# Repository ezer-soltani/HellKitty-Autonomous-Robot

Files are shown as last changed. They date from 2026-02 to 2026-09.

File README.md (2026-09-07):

# 🐱 HellKitty — Autonomous Combat Mobile Robot
### High-Performance Embedded Robotics Platform: STM32G431 (ARM Cortex-M4F @ 170MHz) | FreeRTOS Real-Time Architecture | Custom 4-Layer PCB

<p align="center">
  HellKitty Autonomous Mobile Robot
</p>

<p align="center">
  
  
  
  
  
</p>

---

## ⚡ Executive Engineering Summary

**HellKitty** is an industrial-grade autonomous combat robot engineered for high-speed table-top arena navigation ("Cat & Mouse" adversarial game logic). Designed from bare silicon up to deterministic application-layer control, the platform combines custom **4-layer power/signal mixed PCB hardware**, **bare-metal C peripheral drivers**, and a **preemptive FreeRTOS real-time architecture**.

The robot executes simultaneous 360° laser perception (YDLIDAR X2 @ 115.2 kbps via DMA), 4-quadrant edge/void Time-of-Flight monitoring (VL53L0X @ 100 Hz), high-G collision detection (ADXL343 accelerometer), dual closed-loop velocity PID regulation (TIM2/TIM4 hardware encoder quadrature decoding @ 100 Hz), and dynamic state-machine tactical transitions under strict deterministic latency constraints.

```
+----------------------------------------------------------------------------------------------------+
|                                    HELLKITTY SYSTEM BENCHMARKS                                     |
+--------------------------+-------------------------------------------------------------------------+
| Core Frequency           | 170 MHz (ARM Cortex-M4F with hardware FPU & DSP instructions)           |
| Control Loop Frequency   | 100 Hz deterministic periodic execution (vTaskDelayUntil)               |
| Edge Safety Latency      | < 10 ms hardware-level emergency stop & auto-evacuation override        |
| LiDAR Data Stream        | Circular DMA buffer (1024 B) with zero-copy packet state-machine parser |
| Sensor Bus Topology      | I2C1 (Fast Mode 400 kHz) with FreeRTOS Mutex Priority Inheritance       |
| Dynamic Power Delivery   | 5.5V-12V input -> 5V @ 3A Buck (MP1475) -> 3.3V Low-Noise LDO (BU33SD5)  |
| Motor Control Drive      | Dual ZXBM5210-SP H-Bridges (3A peak, dynamic braking, 20 kHz PWM)       |
+--------------------------+-------------------------------------------------------------------------+
```

---

## 🏗️ System Architecture

The robot's firmware and hardware layers are decoupled through strict hardware abstraction and thread-safe real-time communication mechanisms:

```mermaid
graph TD
    %% Subsystem Grouping
    subgraph SENSORS["Perception & Telemetry Hardware"]
        LIDAR["YDLIDAR X2\n(360° 2D Laser Rangefinder)"]
        TOF["4x VL53L0X ToF\n(Quadrants: FL, FR, RL, RR)"]
        IMU["ADXL343\n(3-Axis Accelerometer)"]
        ENC["2x Quadrature Encoders\n(2048 CPR / Wheel)"]
        BT["HC-05 Bluetooth\n(Telemetry / Remote Shell)"]
    end

    subgraph HARDWARE_IF["STM32G431 Microcontroller Peripherals"]
        UART2_DMA["USART2 + Circular DMA\n(115200 baud, 1024B Buffer)"]
        I2C1_BUS["I2C1 Fast Mode (400kHz)\n(Addresses: 0x54, 0x56, 0x58, 0x5A, 0xA6)"]
        TIM_ENC["TIM2 (32-bit) & TIM4 (16-bit)\nHardware Encoder Interface Mode"]
        UART3_IT["USART3 RX Interrupt\n(Byte-by-byte parser)"]
        TIM3_PWM["TIM3 4-Channel PWM\n(20 kHz Motor Drive)"]
        GPIO_CTRL["GPIO Output / Status LEDs\n(XSHUT, Brake, Status LEDs)"]
    end

    subgraph RTOS_LAYER["FreeRTOS Preemptive Kernel"]
        MUTEX_I2C{{"xI2C1Mutex\n(Priority Inheritance)"}}
        MUTEX_UART{{"xUARTMutex\n(Thread-Safe Printf)"}}
        
        TASK_SAFETY["vSafetyTask\n(Priority 3 | 100 Hz)\nEdge Void & Fault Protection"]
        TASK_CONTROL["vControlTask\n(Priority 4 | 100 Hz)\nPID, Odometry, Motor Output"]
        TASK_LIDAR["vLidarTask\n(Priority 2 | 10-100 Hz)\nDMA Stream & Cluster Tracker"]
        TASK_IMU["vImuTask\n(Priority 1 | 20 Hz)\nShock / Tap Detection (>3.5G)"]
        
        OVERRIDE_FLAG[["g_safety_override\n(Atomic Override Flag)"]]
    end

    subgraph CONTROL_LOGIC["Control & Algorithmic Layer"]
        FSM["Strategy FSM\n(SEARCH / ATTACK / FLEE)"]
        PID_L["Left Velocity PID\n(Kp=5.0, Ki=20.0, Anti-Windup)"]
        PID_R["Right Velocity PID\n(Kp=5.0, Ki=20.0, Anti-Windup)"]
        ODOM["Runge-Kutta Odometry\n(x, y, θ state integration)"]
        CLUST["Geometric Clustering\n(Width Filter: 50-300mm)"]
    end

    subgraph ACTUATION["Actuators & Power Systems"]
        H_BRIDGE["Dual ZXBM5210-SP H-Bridges\n(Reversible DC Motor Drivers)"]
        MOTORS["2x Micro Metal Gearmotors\n(Differential Drive Chassis)"]
        STATUS_LED["Cat/Mouse Status Indicator LEDs"]
    end

    %% Connectivity
    LIDAR --> UART2_DMA
    TOF --> I2C1_BUS
    IMU --> I2C1_BUS
    ENC --> TIM_ENC
    BT --> UART3_IT

    UART2_DMA --> TASK_LIDAR
    I2C1_BUS <--> MUTEX_I2C
    MUTEX_I2C <--> TASK_SAFETY
    MUTEX_I2C <--> TASK_IMU
    UART3_IT --> FSM
    TIM_ENC --> TASK_CONTROL

    TASK_LIDAR --> CLUST --> FSM
    TASK_IMU -->|Role Switch Event| FSM
    FSM --> TASK_CONTROL
    
    TASK_CONTROL --> PID_L & PID_R --> TIM3_PWM
    TASK_CONTROL --> ODOM
    TASK_SAFETY -->|Triggers Emergency Evasion| OVERRIDE_FLAG
    OVERRIDE_FLAG -.->|Forces Motor Override| TASK_CONTROL

    TIM3_PWM --> H_BRIDGE --> MOTORS
    GPIO_CTRL --> STATUS_LED
```

---

## ⏱️ FreeRTOS Multitasking & Real-Time Scheduling

The firmware uses **FreeRTOS v10.3.1** with dynamic memory allocation, preemptive scheduling, and priority-inheritance mutexes to guarantee deterministic timing across all subsystems.

### Task Execution Matrix

| Task Name | Priority | Periodicity / Trigger | Stack Size | Shared Resources / IPC | Functional Responsibility |
| :--- | :---: | :---: | :---: | :---: | :--- |
| `vControlTask` | **4 (Highest)** | **100 Hz (10 ms)**<br>`vTaskDelayUntil` | 512 words<br>(2048 B) | Hardware Timers (TIM2/3/4), Target Speeds (`target_speed_lin_x`, `target_speed_ang_z`) | Reads wheel encoders, updates Runge-Kutta odometry, executes dual velocity PID loops with integral anti-windup, computes PWM duty cycles, and applies motor ramping. |
| `vSafetyTask` | **3 (High)** | **100 Hz (10 ms)**<br>Continuous Polling | 256 words<br>(1024 B) | `xI2C1Mutex`, `g_safety_override`, `STATUS_SOURIS_LED` | Polls 4x VL53L0X ToF range registers. If distance to table surface exceeds 200 mm (void/cliff detected), asserts atomic override flag, cuts motor PWM, and commands automated pivot-and-reverse escape trajectory. |
| `vLidarTask` | **2 (Normal)** | **10 Hz (100 ms)**<br>(DMA Polled @ 100 Hz) | 512 words<br>(2048 B) | `huart2` Circular DMA buffer, `xUARTMutex`, `g_target` | Processes raw bytes from circular DMA, validates packet headers (`0xAA 0x55`) and XOR checksums, performs geometric angle correction, clusters contiguous obstacle points, and tracks closest target. |
| `vImuTask` | **1 (Low)** | **20 Hz (50 ms)**<br>Periodic Delay | 256 words<br>(1024 B) | `xI2C1Mutex`, `Strategy_ToggleRole()` | Reads ADXL343 3-axis acceleration registers over I2C. Evaluates hardware `SINGLE_TAP` shock interrupt (>3.5G threshold) with 2000 ms debounce to switch between Cat (Predator) and Mouse (Prey) combat states. |

### Shared Resource Arbitration & Synchronization

```c
// Example: Thread-safe I2C bus acquisition with Priority Inheritance
if (xSemaphoreTake(xI2C1Mutex, portMAX_DELAY) == pdTRUE) {
    status = ADXL343_ReadAxes(&hi2c1, &accel_data);
    if (ADXL343_CheckShock(&hi2c1) && g_safety_override == 0) {
        shock_detected = 1;
    }
    xSemaphoreGive(xI2C1Mutex);
}
```

1. **I2C1 Bus Contention:** The `xI2C1Mutex` protects the single I2C peripheral shared between the 4x VL53L0X ToF rangefinders and the ADXL343 IMU. Priority inheritance guarantees that if the low-priority `vImuTask` holds the bus when `vSafetyTask` wakes up, `vImuTask` temporarily inherits Priority 3, preventing unbounded priority inversion.
2. **LiDAR Circular DMA Buffer:** Direct Memory Access on USART2 writes directly to a 1024-byte SRAM ring buffer without CPU interrupt thrashing. The task tracks hardware `CNDTR` counter offsets to parse complete frames asynchronously.
3. **Safety Override Interlock:** An atomic flag `g_safety_override` decouples normal FSM navigation from the anti-fall maneuver. When asserted, `vControlTask` suspends trajectory setpoints until the robot returns to safe bounds.

---

## 🖨️ Hardware Design & Custom 4-Layer PCB

The robot is built around a custom **4-layer impedance-controlled PCB** engineered in KiCad 9.0, optimized for high current density, low EMI, and clean power distribution.

<p align="center">
  4-Layer PCB 3D CAD Model
</p>

### PCB Layer Stackup (1.6 mm Total Thickness, FR4)

| Layer | Name | Type | Copper Thickness | Dielectric Spacing | Functional Allocation |
| :---: | :--- | :---: | :---: | :---: | :--- |
| **L1** | `F.Cu` (Top) | Signal | 35 µm (1 oz) | — | High-speed digital signals (SWD, USART, I2C, SPI), MCU breakout, sensor connectors. |
| **—** | Dielectric 1 | Prepreg (FR4) | — | 0.10 mm (\(\varepsilon_r = 4.5\)) | High capacitive coupling to ground plane. |
| **L2** | `In1.Cu` (Inner 1) | Power / Plane | 35 µm (1 oz) | — | **Continuous Solid Ground Plane (GND)** for unbroken return current paths and EMI reduction. |
| **—** | Dielectric 2 | Core (FR4) | — | 1.24 mm (\(\varepsilon_r = 4.5\)) | Structural core isolation. |
| **L3** | `In2.Cu` (Inner 2) | Power / Plane | 35 µm (1 oz) | — | **Power Distribution Plane (PWR)**: Split polygon pours for `+5V`, `+3.3V`, and `VBAT`. |
| **—** | Dielectric 3 | Prepreg (FR4) | — | 0.10 mm (\(\varepsilon_r = 4.5\)) | High capacitive coupling to bottom layer. |
| **L4** | `B.Cu` (Bottom) | Signal | 35 µm (1 oz) | — | High-current motor H-bridge power routing, thermal relief dissipation, and test points. |

### Component & Power Distribution Architecture

| Subsystem | Component / IC | Interface | Specifications & Operational Role |
| :--- | :--- | :---: | :--- |
| **MCU** | **STM32G431CBU6** (UFQFPN48) | SWD / STDC14 | ARM Cortex-M4F @ 170 MHz, 128 KB Flash, 32 KB SRAM, hardware FPU/DSP, CORDIC math unit. |
| **Step-Down Buck** | **MPS MP1475DJ-LF-P** | Switching Reg | 500 kHz synchronous buck converter converting 2S/3S LiPo battery (7.4V–11.1V) to a stable 5.0V @ 3.0A rail. |
| **Low-Noise LDO** | **ROHM BU33SD5WG-TR** | Linear Reg | High PSRR, ultra-low dropout linear regulator stepping down 5.0V to 3.3V for MCU core and analog peripherals. |
| **Motor Drivers** | **2x Diodes Inc. ZXBM5210-SP** | TIM3 PWM / GPIO | Reversible H-Bridge drivers (3V–18V, 0.85A continuous, 3.0A peak, SOIC-8EP) with dynamic braking and cross-conduction protection. |
| **LiDAR Sensor** | **YDLIDAR X2** | USART2 + DMA | 360° 2D triangulation laser rangefinder (8 Hz rotational scan frequency, 0.12m–8.0m range, 3 kHz sample rate). |
| **Cliff / ToF Array** | **4x STMicroelectronics VL53L0X** | I2C1 + 4x XSHUT | Time-of-Flight ranging sensors dynamically re-addressed (0x54, 0x56, 0x58, 0x5A) for four-corner table edge monitoring. |
| **IMU / Shock** | **Analog Devices ADXL343BCCZ** | I2C1 + INT2 | 3-axis ultra-low power digital accelerometer configured for `SINGLE_TAP` interrupt capture (>3.5G collision detection). |
| **Encoders** | **2x Quadrature Optical/Magnetic** | TIM2 / TIM4 | Dual-channel differential quadrature encoder feedback (2048 counts per wheel revolution in 4x mode). |
| **Telemetry / Comms**| **HC-05 Bluetooth Module** | USART3 @ 9600bd | Bidirectional UART telemetry bridge for real-time telemetry streaming and remote state control. |

### KiCad Schematic Sheet Index

The complete schematic design is partitioned into modular hierarchical sheets inside [`hardware/`](hardware/):

| Schematic Sheet | Source File | Description |
| :--- | :--- | :--- |
| **Root Top Sheet** | [`Projet_Robot.kicad_sch`](hardware/Projet_Robot.kicad_sch) | Top-level interconnections, hierarchical bus links, and module connectors. |
| **MCU & Clocks** | [`µcontrolleur.kicad_sch`](hardware/µcontrolleur.kicad_sch) | STM32G431 pinout, STDC14 debug connector, external 8 MHz crystal, bypass capacitors, and status LEDs. |
| **Power Regulators** | [`regulateurs.kicad_sch`](hardware/regulateurs.kicad_sch) | MP1475 buck regulator, BU33SD5 LDO, LC output filtering, reverse-polarity protection, and slide power switch. |
| **Sensor Array** | [`capteur.kicad_sch`](hardware/capteur.kicad_sch) | 4x VL53L0X ToF connectors with XSHUT lines, ADXL343 accelerometer layout, and YDLIDAR / HC-05 headers. |
| **Motor Driver 1 & 2** | [`moteur1.kicad_sch`](hardware/moteur1.kicad_sch) | Dual ZXBM5210-SP H-Bridges, flyback suppression capacitors, test points, and JST-XH encoder/motor connectors. |

---

## 💻 Low-Level Driver & Algorithmic Implementation

### 1. YDLIDAR X2 Circular DMA Driver & Packet Parsing

The LiDAR stream transmits continuous variable-length point frames at 115200 baud over `USART2`. To eliminate CPU byte-by-byte interrupts, DMA operates in circular ring-buffer mode (`LIDAR_DMA_BUFFER_SIZE = 1024`):

```c
// Zero-overhead ring buffer processing in vLidarTask
uint16_t pos = LIDAR_DMA_BUFFER_SIZE - __HAL_DMA_GET_COUNTER(huart2.hdmarx);
if (pos != old_pos) {
    if (pos > old_pos) {
        ydlidar_process_data(&lidar_dma_buffer[old_pos], pos - old_pos);
    } else {
        ydlidar_process_data(&lidar_dma_buffer[old_pos], LIDAR_DMA_BUFFER_SIZE - old_pos);
        if (pos > 0) ydlidar_process_data(&lidar_dma_buffer[0], pos);
    }
    old_pos = pos;
}
```

#### Frame Decoding State Machine & Validation
1. **Header Synchronization:** Scans for sequence `0xAA 0x55`.
2. **Header Parsing:** Reads Packet Type (`CT`), Sample Count (`LSN`), First Sample Angle (`FSA`), and Last Sample Angle (`LSA`).
3. **XOR Checksum Verification:** Computes 16-bit folded XOR checksum over the full packet structure and rejects corrupted frames:
   $$\text{Checksum} = \bigoplus_{i=0}^{N-1} \text{Word}_i$$
4. **Geometric Angle Correction:** Corrects triangulation parallax distortion for near-field obstacles:
   $$\theta_{\text{corrected}} = \theta_{\text{raw}} + \arctan\left(21.8 \cdot \frac{155.3 - d}{155.3 \cdot d}\right) \cdot \frac{180^\circ}{\pi}$$
5. **Spatial Clustering & Object Discrimination:** Contiguous points with spatial distance variation $< \Delta_{\text{thresh}}$ are grouped into object clusters. Physical width is computed via polar chord projection:
   $$W_{\text{object}} = 2 \cdot d_{\text{avg}} \cdot \tan\left(\frac{\theta_{\text{width}}}{2}\right)$$
   *Clusters with $50\,\text{mm} \le W \le 300\,\text{mm}$ and $d \le 1200\,\text{mm}$ are classified as adversarial robots; static wall boundaries and arena artifacts are filtered out.*

---

### 2. Multi-Device Dynamic I2C Bootstrapping (4x VL53L0X)

All four VL53L0X Time-of-Flight sensors power up with the identical default I2C address (`0x29 / 0x52`). The custom driver performs a deterministic hardware-timed bootstrap:

```mermaid
sequenceDiagram
    participant MCU as STM32G431 (Master)
    participant T1 as TOF1 (Front-Right)
    participant T2 as TOF2 (Front-Left)
    participant T3 as TOF3 (Rear-Left)
    participant T4 as TOF4 (Rear-Right)

    Note over MCU,T4: Reset Phase: Drive all XSHUT pins LOW
    MCU->>T1: XSHUT1 = 0
    MCU->>T2: XSHUT2 = 0
    MCU->>T3: XSHUT3 = 0
    MCU->>T4: XSHUT4 = 0
    MCU->>MCU: Delay 20ms

    Note over MCU,T1: Stage 1: Initialize TOF 1
    MCU->>T1: XSHUT1 = 1 (Wake up)
    MCU->>T1: Write Reg 0x8A -> Re-address to 0x54
    MCU->>T1: Load Calibration & Start Continuous Mode

    Note over MCU,T2: Stage 2: Initialize TOF 2
    MCU->>T2: XSHUT2 = 1 (Wake up)
    MCU->>T2: Write Reg 0x8A -> Re-address to 0x56
    MCU->>T2: Load Calibration & Start Continuous Mode

    Note over MCU,T3: Stage 3: Initialize TOF 3
    MCU->>T3: XSHUT3 = 1 (Wake up)
    MCU->>T3: Write Reg 0x8A -> Re-address to 0x58
    MCU->>T3: Load Calibration & Start Continuous Mode

    Note over MCU,T4: Stage 4: Initialize TOF 4
    MCU->>T4: XSHUT4 = 1 (Wake up)
    MCU->>T4: Write Reg 0x8A -> Re-address to 0x5A
    MCU->>T4: Load Calibration & Start Continuous Mode
```

---

### 3. Closed-Loop Motion Control, Odometry & State Machine

```
              +-------------------------------------------------------------+
              |                      STRATEGY FSM                           |
              |       (SEARCH -> ATTACK [Cat] / FLEE [Mouse])               |
              +-------------------------------------------------------------+
                                   |                     |
                      v_lin (target_speed_lin_x)    v_ang (target_speed_ang_z)
                                   |                     |
                                   v                     v
              +-------------------------------------------------------------+
              |                DIFFERENTIAL KINEMATICS                      |
              |  ω_L = (v_lin - v_ang * L/2) / R                            |
              |  ω_R = (v_lin + v_ang * L/2) / R                            |
              +-------------------------------------------------------------+
                         |                                  |
                   Target ω_L                         Target ω_R
                         |                                  |
                         v                                  v
              +--------------------+             +--------------------+
              |  PID LEFT (Motor2) |             | PID RIGHT (Motor1) |
              |  Kp=5.0, Ki=20.0   |             | Kp=5.0, Ki=20.0    |
              |  Anti-Windup Clamped|             | Anti-Windup Clamped|
              +--------------------+             +--------------------+
                         |                                  |
                     PWM_Duty_L                         PWM_Duty_R
                         |                                  |
                         v                                  v
              +--------------------+             +--------------------+
              | TIM3 CH3/CH4 (PWM) |             | TIM3 CH1/CH2 (PWM) |
              +--------------------+             +--------------------+
```

#### Parallel PID Velocity Control with Anti-Windup
$$\text{Output}(t) = K_p \cdot e(t) + K_i \int_0^t e(\tau)\,d\tau + K_d \frac{de(t)}{dt}$$

To prevent integrator windup during motor saturation or abrupt stops:
$$\text{Integral}_{\text{clamped}} = \max\left(-\text{Max}_{\text{int}}, \min\left(\text{Max}_{\text{int}}, \text{Integral} + e(t) \cdot \Delta t\right)\right)$$

#### Runge-Kutta / Midpoint Odometry Position Integration
Wheel speeds \(\omega_L, \omega_R\) are converted to linear displacement at \(\Delta t = 10\,\text{ms}\):
$$v_{\text{robot}} = \frac{v_R + v_L}{2}, \quad \omega_{\text{robot}} = \frac{v_R - v_L}{L_{\text{track}}}$$
$$\Delta \theta = \omega_{\text{robot}} \cdot \Delta t, \quad \theta_{\text{mid}} = \theta_k + \frac{\Delta \theta}{2}$$
$$x_{k+1} = x_k + v_{\text{robot}} \cdot \cos(\theta_{\text{mid}}) \cdot \Delta t$$
$$y_{k+1} = y_k + v_{\text{robot}} \cdot \sin(\theta_{\text{mid}}) \cdot \Delta t$$
$$\theta_{k+1} = \theta_k + \Delta \theta \pmod{2\pi}$$

---

## 🛠️ Build, Flash & Deployment Guide

### Hardware Requirements
- **Target Hardware:** HellKitty Custom PCB (with STM32G431CBU6)
- **Debugger / Programmer:** ST-Link V2 / V3 or J-Link (via standard SWD STDC14 connector)
- **Power Supply:** 2S LiPo Battery (7.4V) or Benchtop Power Supply (7.0V–12.0V, 3A limit)

### Software & Toolchain Prerequisites
- **Toolchain:** `arm-none-eabi-gcc` (v10.3 or higher)
- **IDE:** STM32CubeIDE (v1.14.0+) or VS Code with Cortex-Debug / CMake
- **Flashing Tools:** `STM32CubeProgrammer`, `openocd`, or `st-flash`
- **Telemetry Visualizer:** Python 3.8+ (`pyserial`, `matplotlib`, `numpy`)

---

### Step-by-Step Compilation & Flashing

#### Option A: Using STM32CubeIDE (GUI)
1. Launch STM32CubeIDE and select `File -> Import -> Existing Projects into Workspace`.
2. Browse to the cloned `firmware/` directory and click **Finish**.
3. Select the build configuration (`Release` or `Debug`).
4. Click **Project -> Build All** (`Ctrl+B`).
5. Connect your ST-Link to the onboard STDC14 connector, then click **Run -> Run** (`Ctrl+F11`).

#### Option B: Using Command Line & OpenOCD (CLI)
```bash
# 1. Clone the repository
git clone https://github.com/ezer-soltani/HellKitty-Autonomous-Robot.git
cd HellKitty-Autonomous-Robot

# 2. Flash binary via OpenOCD with ST-Link
openocd -f interface/stlink.cfg -f target/stm32g4x.cfg \
        -c "program firmware/Debug/Firmware_Robot.elf verify reset exit"

# Alternatively, using STM32CubeProgrammer CLI:
STM32_Programmer_CLI -c port=SWD -w firmware/Debug/Firmware_Robot.bin 0x08000000 -v -rst
```

---

### Real-Time LiDAR Visualizer & Telemetry Setup

A custom Python polar visualizer is included in [`scripts/visualizer.py`](scripts/visualizer.py) for real-time laser point-cloud streaming over serial:

```bash
# Install visualizer dependencies
pip install pyserial matplotlib numpy

# Run the real-time visualizer (adjust port to your serial device, e.g. COM3 or /dev/ttyUSB0)
python scripts/visualizer.py
```

<p align="center">
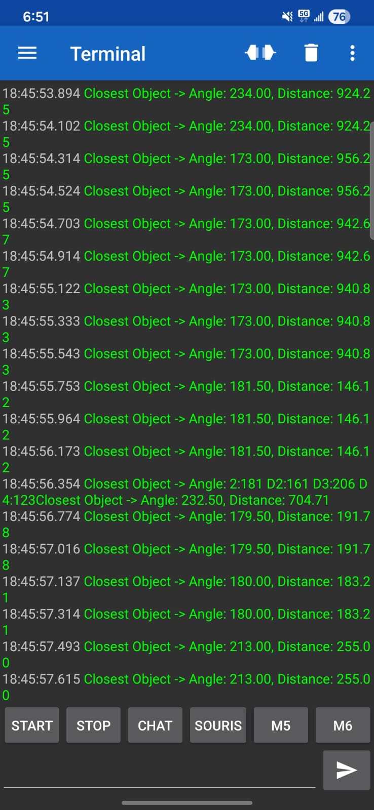
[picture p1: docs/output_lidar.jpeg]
LiDAR Output Visualization
  
</p>

### Remote Shell & Bluetooth Command Protocol

Connect via Bluetooth terminal (HC-05 @ 9600 baud) or ST-Link Virtual COM Port (USART1 @ 115200 baud):

| Command String | Firmware Handler | Action Performed |
| :---: | :--- | :--- |
| `START\n` | `Strategy_SetEnabled(1)` | Enables motor outputs and activates the Strategy FSM. |
| `STOP\n` | `Strategy_SetEnabled(0)` | Emergency stop: forces motor PWM to 0% and clears setpoints. |
| `CHAT\n` | `Strategy_SetRole(ROLE_CHAT)` | Manually sets combat mode to **Cat (Predator)**. Green LED on. |
| `SOURIS\n`| `Strategy_SetRole(ROLE_SOURIS)`| Manually sets combat mode to **Mouse (Prey)**. Red LED on. |

---

## 📂 Repository Structure

```
HellKitty-Autonomous-Robot/
├── firmware/                       # Embedded STM32 Firmware
│   ├── Core/
│   │   ├── Drivers/                # Custom Bare-Metal / HAL Component Drivers
│   │   │   ├── hc-05_bluetooth.c/h # Bluetooth command interpreter & telemetry
│   │   │   ├── imu.c/h             # ADXL343 I2C driver & shock interrupt config
│   │   │   ├── lidar.c/h           # YDLIDAR X2 DMA parser & object clustering
│   │   │   ├── motor.c/h           # H-Bridge PWM & hardware encoder interface
│   │   │   ├── odometry.c/h        # Runge-Kutta differential drive odometry
│   │   │   ├── pid.c/h             # Closed-loop velocity PID with anti-windup
│   │   │   └── tof.c/h             # 4x VL53L0X dynamic I2C bootstrap driver
│   │   ├── Inc/                    # Application Headers & Peripheral Configs
│   │   │   ├── FreeRTOSConfig.h    # Kernel configuration (Preemption, Heap, Priorities)
│   │   │   ├── main.h              # Pin definitions & hardware clock mappings
│   │   │   └── strategy.h          # FSM state declarations & game logic
│   │   └── Src/                    # RTOS Tasks & HAL Peripheral Initialization
│   │       ├── app_freertos.c      # FreeRTOS task implementations & mutex definitions
│   │       ├── main.c              # System initialization & clock tree setup (170MHz)
│   │       └── strategy.c          # Tactical FSM (SEARCH / ATTACK / FLEE)
│   ├── Drivers/                    # STMicroelectronics CMSIS & G4 HAL Drivers
│   ├── Middlewares/                # FreeRTOS Real-Time Kernel Source Code
│   ├── Firmware_Robot.ioc          # STM32CubeMX Hardware Configuration Project
│   └── STM32G431CBUX_FLASH.ld      # GCC Linker Script (Memory Map layout)
├── hardware/                       # KiCad 9.0 Electronic CAD Project
│   ├── Projet_Robot.kicad_pcb      # 4-Layer mixed-signal PCB layout
│   ├── Projet_Robot.kicad_sch      # Top-level hierarchical schematic
│   ├── µcontrolleur.kicad_sch      # STM32G431 MCU schematic sheet
│   ├── regulateurs.kicad_sch       # MP1475 buck & BU33SD5 LDO power regulators
│   ├── capteur.kicad_sch           # VL53L0X ToF, ADXL343 IMU, and sensors
│   ├── moteur1.kicad_sch           # ZXBM5210-SP motor driver H-Bridge circuit
│   └── Gerbers_hellokitty/         # Production-ready Gerber & Drill manufacturing files
├── scripts/
│   └── visualizer.py               # Python Matplotlib polar LiDAR real-time telemetry
├── docs/                           # Datasheets, Architecture Diagrams & Test Reports
│   ├── Firmware_Architecture.md    # In-depth architectural specification
│   ├── Tasks_FreeRTOS.md           # Task execution & priority analysis
│   ├── schema_arch.png             # System block diagram
│   └── YDLIDAR X2 Data Sheet.pdf   # Component datasheets
├── LICENSE                         # MIT License
└── README.md                       # Project Technical Showcase & Documentation
```

---

## 👨‍💻 Engineering Team & Contributors

Developed at **ENSEA** (Graduate School of Electrical and Computer Engineering) within the *Electronics & Embedded Systems (ESE)* department:

- **Ezer Soltani** — *Embedded Software & Firmware Lead (FreeRTOS, Drivers, Control & Odometry)* — [GitHub](https://github.com/ezer-soltani)
- **Aymen Ben Jemaa** — *Hardware & PCB Design Engineer (KiCad 4-Layer Board, Power Delivery)* — [GitHub](https://github.com/aymen-bj)
- **Serine Rouabah** — *Perception, Sensor Integration & Algorithm Development* — [GitHub](https://github.com/serine-rouabah)

---

## 📜 License

This project is licensed under the **MIT License** — see the [LICENSE](LICENSE) file for complete details.

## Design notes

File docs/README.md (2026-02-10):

# 🐱 **HellKitty - Projet Robot Chat & Souris**







---

## 📜 **Description**
**HellKitty** est un robot mobile autonome conçu pour la compétition de "Chat et Souris".
🎯 **Objectif :** Survivre sur une table sans bordure, détecter l'adversaire via un LIDAR, et alterner dynamiquement entre les rôles de **Prédateur** (Chat) et de **Proie** (Souris) en fonction des chocs reçus.

Ce projet est réalisé dans le cadre de la dernière année de la filière **Électronique et Systèmes Embarqués (ESE)** de l'ENSEA.

### **Les contributeurs :**
- 👨‍💻 **Serine**
- 👨‍💻 **Aymen**
- 👨‍💻 **Ezer**

---

## 📚 **Table des matières**
1. [📖 Contexte & Règles](#-contexte--règles)
2. [📐 Architecture Système](#-architecture-système)
3. [🧠 Stratégie & IA](#-stratégie--ia)
4. [📡 Connectivité & Debug](#-connectivité--debug)
5. [📚 Explication Technique](#-explication-technique)
6. [🔧 Matériel utilisé](#-matériel-utilisé)
7. [🚀 État d'avancement](#-état-davancement)

---

## 📖 **Contexte & Règles**
Le défi consiste à concevoir un système embarqué complet (Hardware + Firmware) capable de :
1.  **Ne jamais tomber** de la table (Sécurité critique).
2.  **Localiser** un adversaire dynamique via LIDAR.
3.  **Changer de rôle** : Le robot commence en "Chat". S'il subit une collision (détectée par IMU), il devient "Souris" et doit fuir.

---

## 📐 **Architecture Système**

### **Architecture Logicielle (FreeRTOS)**
Le firmware repose sur un OS temps réel pour garantir la réactivité et la ségrégation des tâches critiques.

| Tâche | Priorité | Fréquence | Rôle |
| :--- | :---: | :---: | :--- |
| **vSafetyTask** | ⭐⭐⭐ (High) | *Event (EXTI)* | Activée par interruption TOF. Arrêt d'urgence et manœuvre de recul prioritaire. |
| **vControlTask** | ⭐⭐ (Med) | 100Hz | Gestion de la stratégie, Tracking cible, PID Moteur et Odométrie. |
| **vLidarTask** | ⭐⭐ (Med) | 10Hz | Parsing DMA, Filtrage géométrique et Tracking temporel de l'ennemi. |
| **vImuTask** | ⭐ (Low) | 20Hz | Détection de chocs (Tap detection) pour le changement de rôle. |

---

## 🧠 **Stratégie & IA**

Le robot utilise une **Machine à États Finis (FSM)** complexe couplée à un **Tracking Temporel** de la cible.

### **1. Les Rôles (Game Logic)**
*   **🐱 CHAT (Led Verte) :** Le robot cherche activement l'ennemi pour le percuter.
*   **🐭 SOURIS (Led Rouge) :** Le robot cherche l'ennemi pour le fuir (s'orienter à l'opposé).
*   **🔄 Basculement :** Un choc > 3.5G détecté par l'accéléromètre (ADXL343) inverse instantanément le rôle (avec anti-rebond de 2s).

### **2. Les États Comportementaux**
*   **SEARCH (Recherche) :** Rotation sur place (~3 rad/s) pour scanner l'environnement à 360°.
*   **ATTACK (Poursuite) :**
    *   Verrouillage de la cible.
    *   Correction angulaire (PID) pour rester face à l'ennemi.
    *   Vitesse linéaire : **200 mm/s**.
*   **FLEE (Fuite) :**
    *   Calcul du vecteur opposé à la menace (Cible à 180°).
    *   Demi-tour rapide (6 rad/s).
    *   Fuite en ligne droite à **250 mm/s**.

### **3. Target Tracking (Mémoire)**
Pour éviter les mouvements erratiques, le robot utilise un filtre Alpha ($\alpha=0.3$) sur la position de l'ennemi et garde en mémoire la dernière position connue pendant **1 seconde** si le LIDAR perd le visuel.

---

## 📡 **Connectivité & Debug**

Le robot intègre un module Bluetooth **HC-05** redirigeant la sortie standard (`printf`).

### **Commandes Distantes**
Il est possible de piloter le robot depuis un smartphone/PC (115200 bauds) :
*   `START` : Active les moteurs et la stratégie.
*   `STOP` : Arrêt d'urgence logiciel (Moteurs à 0).
*   `CHAT` : Force le mode Chasseur.
*   `SOURIS` : Force le mode Proie.

### **Logs en Temps Réel**
Le robot renvoie son état interne :
> `Strategy: Target Found! Switching to ATTACK`
> `IMU: SHOCK DETECTED! Toggling Role.`
> `Safety: VOID DETECTED! Evacuating...`

---

## 📚 **Explication Technique**

### 1. 👁️ Perception LIDAR (YDLIDAR X2)
Nous n'utilisons pas simplement les données brutes. Le driver implémente un pipeline de traitement avancé :
*   **Correction Géométrique :** Compensation de la distorsion angulaire liée à la rotation.
*   **Segmentation :** Calcul de la **largeur physique** des objets ($L = 2 \cdot d \cdot \tan(\theta/2)$).
    *   Seuls les objets de **5cm à 30cm** sont considérés comme des robots.
    *   Les murs et pieds de table sont ignorés.

### 2. 🛡️ Barrière Immatérielle (4x VL53L0X)
Quatre capteurs TOF sont disposés aux coins du robot.
*   **Override Hardware :** Si $d > 500mm$ (vide), une interruption déclenche `vSafetyTask`.
*   Cette tâche **bloque** toutes les commandes de la stratégie pour exécuter une séquence de sauvetage inviolable.

### 3. ⚙️ Asservissement & Odométrie
*   **PID Vitesse :** $Kp=5.0, Ki=20.0$. Réponse rapide (< 100ms) sans dépassement.
*   **Odométrie :** Suivi de position ($x, y, \theta$) par intégration de Runge-Kutta.

---

## 🔧 **Matériel utilisé**

*   **MCU :** STM32G431CBU6 (Cortex-M4 170MHz, FPU).
*   **LIDAR :** YDLIDAR X2 (UART/DMA).
*   **TOF :** 4x VL53L0X (I2C) adressés dynamiquement.
*   **IMU :** ADXL343 (I2C) pour les chocs.
*   **Coms :** Module Bluetooth HC-05.
*   **Moteurs :** DC avec encodeurs quadratiques (2048 ticks/tour).

---

## 🚀 **État d'avancement**

### ✅ Terminés & Validés
- [x] **Architecture OS** (Tasks, Mutex, Semaphores).
- [x] **Drivers Bas Niveau** (Tous capteurs + Moteurs).
- [x] **Asservissement PID** (Réglé et stable).
- [x] **Sécurité Anti-Chute** (Infaillible).
- [x] **Stratégie Complète** (Search, Attack, Flee).
- [x] **Logique de Jeu** (Changement de rôle par choc).
- [x] **Connectivité Bluetooth** (Télécommande & Logs).

### 📅 Perspectives
- Optimisation de la vitesse de rotation en combat pour éviter le dérapage.
- Ajout d'une stratégie d'évitement prédictif des murs (SLAM simplifié).

---

## 📄 **Licence**
Projet développé à l'ENSEA. Code source sous licence MIT.

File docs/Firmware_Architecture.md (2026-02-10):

# Architecture Firmware Robot (STM32G4 + FreeRTOS)

Ce document décrit l'architecture logicielle proposée pour la migration du firmware vers un système temps réel (FreeRTOS). L'architecture est organisée en couches (Layers) pour découpler le matériel de la logique décisionnelle.

## 1. Diagramme Architecturel Global

Le diagramme ci-dessous illustre les interactions entre les périphériques matériels, les drivers HAL, les drivers de composants, les algorithmes de contrôle et les tâches FreeRTOS.

```mermaid
graph BT
    %% On utilise BT (Bottom-Top) pour empiler les couches du bas vers le haut

    %% --- 1. COUCHE HARDWARE (Tout en bas) ---
    subgraph Hardware [Hardware Layer]
        direction BT
        HW_LIDAR[YDLIDAR X2]
        HW_TOF[VL53L0X x4]
        HW_IMU[ADXL343]
        HW_MOT[Moteurs DC]
        HW_ENC[Encodeurs]
        HW_BT[Bluetooth HC-05]
        HW_PC[PC Debug]
    end

    %% --- 2. COUCHE HAL ---
    subgraph HAL [HAL Layer - Low Level]
        direction BT
        UART2[usart.c - UART2]
        I2C1[i2c.c - I2C1]
        TIM3[tim.c - TIM3 PWM]
        TIM2_4[tim.c - TIM2/TIM4 ENC]
        UART3[usart.c - UART3]
        UART1[usart.c - UART1]
        GPIO[gpio.c]
        
        %% Interrupts
        IT_UART2(USART2_IRQHandler)
        IT_TIM(TIM_Update_IT)
    end

    %% LIENS: HARDWARE <--> HAL
    HW_LIDAR <--> UART2
    HW_TOF <--> I2C1
    HW_IMU <--> I2C1
    HW_MOT <--> TIM3
    HW_ENC <--> TIM2_4
    HW_BT <--> UART3
    HW_PC <--> UART1

    %% --- 3. COUCHE DRIVERS ---
    subgraph Drivers [Component Drivers]
        direction BT
        DRV_LIDAR[lidar.c]
        DRV_TOF[tof.c]
        DRV_IMU[imu.c]
        DRV_MOT[motor.c]
        DRV_ENC[encoder.c]
        DRV_COM[bluetooth.c]
    end

    %% LIENS: HAL --> DRIVERS (Flux de données remonte vers le haut)
    UART2 --> DRV_LIDAR
    IT_UART2 -.->|Notify| DRV_LIDAR
    I2C1 <--> DRV_TOF
    I2C1 <--> DRV_IMU
    TIM2_4 -->|Count| DRV_ENC
    UART3 <--> DRV_COM
    UART1 <--> DRV_COM
    GPIO --> DRV_TOF
    
    %% Pour les commandes (vers le bas), on inverse la syntaxe (<--) 
    %% pour garder le Driver au-dessus du HAL visuellement
    TIM3 <-- DRV_MOT
    GPIO <-- DRV_MOT

    %% --- 4. COUCHE HAUTE: ALGOS & RTOS ---
    subgraph HighLevel [Application Layer]
        direction BT
        
        subgraph Algos [Control & Strategy Libs]
            LIB_ODO[odometrie.c]
            LIB_ASSERV[asserv.c]
            LIB_TRAJ[trajectoire.c]
        end

        subgraph RTOS [FreeRTOS Tasks]
            TASK_SAFETY([Task_Safety_Edge\nCRITICAL Prio])
            TASK_IMU([Task_IMU_Acq\nMedium Prio])
            TASK_CONTROL([Task_ControlLoop\nHigh Prio])
            TASK_LIDAR([Task_Lidar\nMedium Prio])
            TASK_STRAT([Task_Strategy\nLow Prio])
            
            %% Objets RTOS
            MUTEX_I2C{Mutex_I2C}
            QUEUE_LIDAR[[Queue_LidarPts]]
            QUEUE_CMDS[[Queue_Commands]]
        end
    end

    %% LIENS: DRIVERS <--> ALGOS (Flux montant et descendant)
    DRV_ENC --> LIB_ODO
    DRV_IMU --> LIB_ODO
    LIB_ODO -->|Pos X,Y| LIB_ASSERV
    LIB_TRAJ -->|Consigne| LIB_ASSERV
    
    %% Commande moteur (Descente): Syntaxe <-- force LIB au dessus de DRV
    DRV_MOT <-- LIB_ASSERV

    %% LIENS: RTOS LOGIC
    %% Interrupt (Bas) réveille Queue (Haut)
    IT_UART2 -.->|Give ISR| QUEUE_LIDAR
    DRV_COM -->|Cmd ISR| QUEUE_CMDS

    %% Taches lisent les Queues/Mutex
    QUEUE_LIDAR -.-> TASK_LIDAR
    QUEUE_CMDS -.-> TASK_STRAT
    
    %% SÉPARATION TOF / IMU sur le Mutex I2C
    TASK_SAFETY -->|Take| MUTEX_I2C
    TASK_IMU -->|Take| MUTEX_I2C
    
    %% Appels de fonctions (Control Flow: Haut vers Bas)
    MUTEX_I2C -.-> DRV_TOF
    MUTEX_I2C -.-> DRV_IMU
    
    %% Safety Action Directe
    TASK_SAFETY ==>|EMERGENCY STOP| DRV_MOT
    
    DRV_LIDAR <-- TASK_LIDAR
    
    %% Data Flow Logic (Flux montant)
    DRV_LIDAR -->|Obstacles| TASK_STRAT

    %% Control Loop Layout
    LIB_ODO <-- TASK_CONTROL
    LIB_ASSERV <-- TASK_CONTROL
    LIB_TRAJ <-- TASK_STRAT
    TASK_CONTROL <.-|Update Setpoint| TASK_STRAT
```

## 2. Description des Modules

### A. Couche Bas Niveau (HAL)
Ce sont les fichiers générés par STM32CubeMX (`Core/Src/`).
*   **`usart.c`** : Configure les UARTs.
    *   *UART2* : Réception DMA circulaire ou IT (Interruption) pour le LIDAR.
    *   *UART3* : Communication Bluetooth.
*   **`i2c.c`** : Gestion du bus I2C1 partagé. **Critique :** Doit être protégé par un Mutex FreeRTOS car accédé par plusieurs drivers (TOF et IMU).
*   **`tim.c`** :
    *   *TIM2 & TIM4* : Mode Encodeur (Lecture matérielle des pas).
    *   *TIM3* : Génération PWM pour les moteurs.

### B. Couche Drivers
Abstraction du matériel. Ces fichiers ne contiennent pas de logique "métier" (pas d'asservissement ici).
*   **`lidar.c`** : Décode les paquets de données (Header `0xAA 55`, Checksum). Stocke les points (Angle, Distance) dans une structure accessible.
*   **`tof.c`** : Initialise les 4 capteurs VL53L0X (gestion des broches XSHUT) et lance les mesures.
*   **`motor.c`** : Conversion pourcentage vitesse (-100 à 100) vers PWM + Direction GPIO.
*   **`encoder.c`** : Lit les registres CNT des timers et gère le dépassement (overflow) pour avoir une valeur en ticks continue.

### C. Couche Algorithmique
Logique pure, indépendante du hardware (pourrait être testée sur PC).
*   **`odometrie.c`** :
    *   Entrée : Différence de ticks encodeurs (gauche/droite).
    *   Sortie : Mise à jour de la position globale robot (x, y, theta).
*   **`asserv.c`** :
    *   Contient les PID (Vitesse et Position/Angle).
    *   Calcule la commande moteur pour atteindre la consigne donnée par la stratégie.
*   **`trajectoire.c`** :
    *   Génère des profils de vitesse (trapèze) ou des points de passage pour aller d'un point A à B.

### D. Tâches FreeRTOS (Ordonnancement)

| Tâche | Priorité | Fréquence | Rôle |
| :--- | :--- | :--- | :--- |
| **Task_TOF** | **Très Haute / Critique** | **30-50 Hz** | **Sécurité.** Lit les 4 TOF (via I2C Mutex). Si distance > seuil (vide détecté), coupe immédiatement les moteurs (`Emergency Stop`) en contournant l'asservissement. |
| **Task_ControlLoop** | **Haute** | **100 Hz (10ms)** | **Temps Réel.** Lit les encodeurs -> Calcule l'odométrie -> Exécute les PIDs -> Applique le PWM moteurs. Doit être régulière. |
| **Task_IMU_Acq** | Moyenne | 20 Hz | Lit l'IMU (via I2C Mutex) pour détecter les chocs ou l'inclinaison. Met à jour l'état global. |
| **Task_Lidar** | Moyenne | Événementiel | Attend des données dans la `Queue_LidarPts` (remplie par l'IRQ UART), décode les trames et met à jour la carte des obstacles. |
| **Task_Strategy** | Basse | 10 Hz | Machine à états (FSM). Analyse les obstacles (LIDAR/TOF), décide de la prochaine action et envoie la consigne (X,Y) à l'asservissement. |

## 3. Gestion des Ressources Partagées

1.  **Bus I2C1 (Mutex_I2C)** :
    *   L'IMU et les 4 TOF sont sur le même bus.
    *   Si `Task_Safety_Edge` est préemptée, elle doit pouvoir prendre le Mutex dès qu'il est libre (mécanisme d'héritage de priorité FreeRTOS).
    *   L'IMU doit être lue dans une tâche moins prioritaire (`Task_IMU_Acq`) pour ne pas retarder la détection de bord.

2.  **Données UART Lidar (Queue + StreamBuffer)** :
    *   L'UART reçoit les octets très vite.
    *   L'ISR (Interrupt Service Routine) doit être très courte : elle pousse les octets dans un `StreamBuffer` ou une `Queue`.
    *   La `Task_Lidar` se réveille quand des données sont disponibles pour les traiter.

```

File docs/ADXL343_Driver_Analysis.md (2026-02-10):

# Analyse et État d'Avancement : Driver Accéléromètre (ADXL343)
**Date de mise à jour :** 09 Décembre 2025
**Statut :** FONCTIONNEL (Intégré dans FreeRTOS)

---

## 1. État Actuel
Le driver de l'accéléromètre est opérationnel et intégré dans le firmware final du robot.
*   **Initialisation :** OK (Message "IMU Init OK" visible).
*   **Communication I2C :** OK (Lecture des IDs et des registres).
*   **Fonctionnalité :** Détection de chocs (Tap Detection) active.
*   **OS :** Tourne dans une tâche FreeRTOS dédiée (`vImuTask`).

## 2. Architecture Implémentée

### A. Driver Bas Niveau (`Core/Drivers/imu.c`)
Le code a été refactorisé pour être "stateless" et thread-safe (via l'appelant).
*   **Structure :** Utilise `HAL_I2C_Mem_Read/Write` avec des timeouts (pas de blocage infini).
*   **Configuration :**
    *   Range : ±2g (Full Resolution).
    *   Data Rate : 100 Hz.
    *   **Tap Threshold :** 2.5g (Actuellement codé en dur).
    *   **Tap Duration :** 10ms.

### B. Intégration FreeRTOS (`Core/Src/app_freertos.c`)
*   **Tâche :** `vImuTask`
*   **Priorité :** `osPriorityBelowNormal` (Priorité 2) - Inférieure au Lidar pour ne pas bloquer la navigation.
*   **Protection :**
    *   **`xI2C1Mutex`** : Crucial. Protège l'accès au bus I2C1 car il sera partagé plus tard avec les capteurs de distance (TOF).
    *   **`xUARTMutex`** : Utilisé pour les `printf` afin d'éviter d'écraser les données du Lidar dans la console.

## 3. Problèmes Rencontrés et Résolus

### Conflit d'affichage UART (Lidar vs IMU)
*   **Symptôme :** Le message "!!! SHOCK DETECTED !!!" spamait la console, empêchant le Lidar d'afficher ses objets.
*   **Cause :** La tâche IMU prenait la main trop souvent et le Lidar n'attendait pas la libération du Mutex UART.
*   **Correction :** 
    1.  Ajout d'un `portMAX_DELAY` (attente infinie) dans la tâche Lidar pour garantir qu'elle finisse par écrire.
    2.  Ajout d'un délai (100ms) dans la tâche IMU.

## 4. Prochaines Étapes (Roadmap)

### Étape A : Réglage de la Sensibilité (URGENT)
Le capteur est actuellement trop sensible ("spam" de détections de chocs).
*   **Action :** Modifier `ADXL343_ConfigShock` dans `app_freertos.c` ou `imu.c`.
*   **Valeurs à tester :** Augmenter le seuil de 2.5g à **3.5g** ou **4g** pour ne détecter que les vrais impacts contre les murs, pas les vibrations des moteurs.

### Étape B : Optimisation par Interruption (Hardware)
Actuellement, la tâche fait du "Polling" (elle demande au capteur "as-tu vu un choc ?" toutes les 100ms).
*   **Objectif :** Utiliser la pin **INT1** du capteur (reliée à `PB13` sur le PCB).
*   **Implémentation :** 
    1.  Configurer `PB13` en mode `GPIO_EXTI`.
    2.  Utiliser un Sémaphore Binaire (`xSemaphoreGiveFromISR`) dans le callback d'interruption.
    3.  La tâche `vImuTask` restera bloquée (`xSemaphoreTake`) tant qu'il n'y a pas de choc (0% CPU usage).

### Étape C : Calcul d'Inclinaison (Fonctionnalité)
Ajouter une fonction pour détecter si le robot va se renverser.
*   **Calcul :** Utiliser `atan2` sur les axes Y et Z pour obtenir l'angle de tangage (Pitch).
*   **Utilité :** Arrêt d'urgence si angle > 45°.

---
**Note pour la reprise :** Commencer par l'**Étape A**. Ouvrir `app_freertos.c` et ajuster les paramètres de `ADXL343_ConfigShock`.

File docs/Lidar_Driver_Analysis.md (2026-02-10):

# Suivi du Développement Driver LIDAR (YDLIDAR X2)
**Date :** 8 Décembre 2025
**Statut :** Prêt pour Test Matériel (Labo)

Ce document résume les travaux effectués sur le driver LIDAR, les choix techniques, et la feuille de route pour l'intégration finale.

---

## 1. Fonctionnalités Implémentées

### A. Parsing & Robustesse
*   **Machine à États Finis (FSM) :** Refonte de la machine à états pour une meilleure robustesse.
    *   **Avant :** États séparés pour `0xAA` puis `0x55`. Risque de désynchronisation sur séquence `0xAA 0xAA 0x55`.
    *   **Après :** État unique `STATE_WAIT_HEADER` avec "fenêtre glissante" sur 2 octets. Détecte la séquence `0xAA 0x55` de manière fiable même en présence d'octets parasites.
*   **Validation :** Vérification du Checksum (XOR) sur l'entête et les données.
*   **Gestion dynamique :** Calcul de la taille du paquet attendu basé sur le champ `LSN` (Sample Quantity).

### B. Mathématiques & Correction
*   **Conversion :** Décodage des angles FSA (Start) et LSA (End) selon la datasheet.
*   **Correction Géométrique :** Implémentation de la formule non-linéaire spécifique au YDLIDAR X2 (nécessaire car triangulation, pas TOF pur) :
    `ang_correct = atan(21.8 * (155.3 - dist) / (155.3 * dist))`
*   **Interpolation :** Calcul linéaire de l'angle pour chaque point intermédiaire du paquet.

### C. Analyse de Données (Clustering)
*   **Buffer Circulaire :** Stockage des distances dans un tableau `g_scan_distances_mm[360]`.
*   **Détection d'Objets (`ydlidar_detect_objects`) :**
    *   Analyse le tableau 360° pour grouper les points contigus.
    *   Critère de rupture : Discontinuité de distance > `DETECT_THRESHOLD` (50mm).
    *   Sortie : Liste d'objets `LidarObject_t` (Distance moyenne, Angle moyen, Taille en points).

### D. Optimisation & Nettoyage
*   **Logs Conditonnels :** Remplacement des `printf` bloquants par une macro `LIDAR_LOG`.
    *   Activé via `#define ENABLE_LIDAR_DEBUG`.
    *   Désactivé par défaut pour la production (gain de performance).
*   **Fix Warnings :** Suppression des variables inutilisées (`start_idx`) signalées par le compilateur.

---

## 2. État du Code de Test (`TEST_LIDAR`)

Le projet `Hellokitty-serine-aymen-ezer/Software/TEST_LIDAR` est configuré pour le test de demain.

*   **Fichiers Clés :**
    *   `Core/Src/ydlidar.c` : Le driver complet.
    *   `Core/Src/main.c` : Boucle de test.
*   **Configuration Actuelle :**
    *   **UART2 + DMA :** Réception en mode circulaire (`HAL_UART_Receive_DMA`).
    *   **Callbacks :** `RxHalfCplt` et `RxCplt` appellent directement `ydlidar_process_data` (OK pour ce test bare-metal, à changer pour FreeRTOS).
    *   **Boucle Main :** Appelle `ydlidar_detect_objects` toutes les 100ms et affiche les résultats.
    *   **Debug :** La macro `ENABLE_LIDAR_DEBUG` est **décommentée** (active) pour voir les logs sur le terminal.

---

## 3. Procédure de Test (Au Labo)

1.  **Matériel :**
    *   Alimentation **7.2V - 12V** pour la carte (Alim Labo).
    *   Le régulateur interne de la carte fournira le **5V** nécessaire au Lidar (Pin VCC moteur Lidar).
    *   Connexion Lidar -> STM32 (UART2).
2.  **Logiciel :**
    *   Flasher le code présent dans `TEST_LIDAR`.
    *   Ouvrir un Terminal Série (TeraTerm/Putty) sur le COM Port du ST-Link (115200 baud).
3.  **Vérification :**
    *   Message "YDLIDAR driver initialized." au reset.
    *   Logs des paquets (Start Angle, End Angle, Checksum...).
    *   **Cible :** Placer un objet devant le Lidar et vérifier les logs :
        `Detected Object X: Angle=... Dist=...`

---

## 4. Prochaines Étapes (Intégration FreeRTOS)

Une fois le test matériel validé, nous intégrerons ce driver dans le firmware final (`Software/Firmware`).

1.  **Création de la Tâche :** `Task_Lidar`.
2.  **Gestion des interruptions :**
    *   L'ISR UART ne doit plus appeler `process_data`.
    *   L'ISR doit envoyer une **Notification** ou écrire dans un **StreamBuffer** FreeRTOS.
3.  **Protection des Données :**
    *   Ajout d'un **Mutex** (`osMutexId`) pour protéger l'accès à `g_scan_distances_mm` et à la liste des objets.
    *   `Task_Lidar` : Lock -> Ecrit -> Unlock.
    *   `Task_Strategy` : Lock -> Lit -> Unlock.
4.  **Stratégie :** Utiliser les objets détectés pour l'évitement d'obstacles.

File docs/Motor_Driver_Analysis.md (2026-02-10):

│  1 #ifndef INC_MOTOR_H_ // Changed from INC_MOTOR_DRIVER_H_ to INC_MOTOR_H_ to match new file name                   │
│  2 #define INC_MOTOR_H_ // Changed from INC_MOTOR_DRIVER_H_ to INC_MOTOR_H_ to match new file name                   │
│  3                                                                                                                   │
│  4 #include "stm32g4xx_hal.h"                                                                                        │
│  5                                                                                                                   │
│  6 typedef struct {                                                                                                  │
│  7     // PWM                                                                                                        │
│  8     TIM_HandleTypeDef* pwm_timer;                                                                                 │
│  9     uint32_t           channel_fwd; // Canal PWM Avant (e.g., TIM_CHANNEL_1)                                      │
│ 10     uint32_t           channel_rev; // Canal PWM Arrière (e.g., TIM_CHANNEL_2)                                    │
│ 11                                                                                                                   │
│ 12     // Encodeur                                                                                                   │
│ 13     TIM_HandleTypeDef* enc_timer;                                                                                 │
│ 14     int32_t            enc_prev_counter; // Stockage précédent pour delta                                         │
│ 15     uint32_t           enc_resolution;   // PPR * 4 (Mode TI1+TI2 si utilisé) ou PPR (e.g., 2000 for 500 PPR      │
│    quadrature)                                                                                                       │
│ 16                                                                                                                   │
│ 17     // Données Physiques                                                                                          │
│ 18     float              speed_rpm;                                                                                 │
│ 19     float              speed_rad_s;                                                                               │
│ 20     int32_t            total_ticks;      // Odométrie absolue                                                     │
│ 21 } Motor_Handle_t;                                                                                                 │
│ 22                                                                                                                   │
│ 23 /**                                                                                                               │
│ 24  * @brief Initializes the motor driver.                                                                           │
│ 25  *        Starts the PWM and encoder timers.                                                                      │
│ 26  * @param hmotor Pointer to the Motor_Handle_t structure.                                                         │
│ 27  */                                                                                                               │
│ 28 void Motor_Init(Motor_Handle_t* hmotor);                                                                          │
│ 29                                                                                                                   │
│ 30 /**                                                                                                               │
│ 31  * @brief Sets the motor speed and direction.                                                                     │
│ 32  * @param hmotor Pointer to the Motor_Handle_t structure.                                                         │
│ 33  * @param pwm_percent PWM duty cycle from -100.0 (full reverse) to +100.0 (full forward).                         │
│ 34  */                                                                                                               │
│ 35 void Motor_SetSpeed(Motor_Handle_t* hmotor, float pwm_percent);                                                   │
│ 36                                                                                                                   │
│ 37 /**                                                                                                               │
│ 38  * @brief Updates the motor speed based on encoder readings.                                                      │
│ 39  *        Should be called periodically (e.g., in a control loop task).                                           │
│ 40  * @param hmotor Pointer to the Motor_Handle_t structure.                                                         │
│ 41  * @param delta_time_s Time elapsed since the last update in seconds.                                             │
│ 42  */                                                                                                               │
│ 43 void Motor_UpdateSpeed(Motor_Handle_t* hmotor, float delta_time_s);                                               │
│ 44                                                                                                                   │
│ 45 #endif /* INC_MOTOR_H_ */     

│  1 #include "motor.h"                                                                                                │
│  2 #include <stdlib.h> // For abs()                                                                                  │
│  3                                                                                                                   │
│  4 /**                                                                                                               │
│  5  * @brief Initializes the motor driver.                                                                           │
│  6  *        Starts the PWM and encoder timers.                                                                      │
│  7  * @param hmotor Pointer to the Motor_Handle_t structure.                                                         │
│  8  */                                                                                                               │
│  9 void Motor_Init(Motor_Handle_t* hmotor) {                                                                         │
│ 10     if (hmotor == NULL) return;                                                                                   │
│ 11                                                                                                                   │
│ 12     // Start PWM channels                                                                                         │
│ 13     HAL_TIM_PWM_Start(hmotor->pwm_timer, hmotor->channel_fwd);                                                    │
│ 14     HAL_TIM_PWM_Start(hmotor->pwm_timer, hmotor->channel_rev);                                                    │
│ 15                                                                                                                   │
│ 16     // Start encoder timer                                                                                        │
│ 17     HAL_TIM_Encoder_Start(hmotor->enc_timer, TIM_CHANNEL_ALL);                                                    │
│ 18                                                                                                                   │
│ 19     // Initialize previous counter value and total ticks                                                          │
│ 20     hmotor->enc_prev_counter = __HAL_TIM_GET_COUNTER(hmotor->enc_timer);                                          │
│ 21     hmotor->total_ticks = 0;                                                                                      │
│ 22     hmotor->speed_rpm = 0.0f;                                                                                     │
│ 23     hmotor->speed_rad_s = 0.0f;                                                                                   │
│ 24 }                                                                                                                 │
│ 25                                                                                                                   │
│ 26 /**                                                                                                               │
│ 27  * @brief Sets the motor speed and direction.                                                                     │
│ 28  * @param hmotor Pointer to the Motor_Handle_t structure.                                                         │
│ 29  * @param pwm_percent PWM duty cycle from -100.0 (full reverse) to +100.0 (full forward).                         │
│ 30  */                                                                                                               │
│ 31 void Motor_SetSpeed(Motor_Handle_t* hmotor, float pwm_percent) {                                                  │
│ 32     if (hmotor == NULL) return;                                                                                   │
│ 33                                                                                                                   │
│ 34     // Clamp PWM percentage to [-100, 100]                                                                        │
│ 35     if (pwm_percent > 100.0f) pwm_percent = 100.0f;                                                               │
│ 36     else if (pwm_percent < -100.0f) pwm_percent = -100.0f;                                                        │
│ 37                                                                                                                   │
│ 38     // Calculate absolute duty cycle                                                                              │
│ 39     uint32_t duty_cycle = (uint32_t)(abs((int)pwm_percent) * hmotor->pwm_timer->Init.Period / 100.0f);            │
│ 40                                                                                                                   │
│ 41     if (pwm_percent > 0) { // Forward                                                                             │
│ 42         __HAL_TIM_SET_COMPARE(hmotor->pwm_timer, hmotor->channel_fwd, duty_cycle);                                │
│ 43         __HAL_TIM_SET_COMPARE(hmotor->pwm_timer, hmotor->channel_rev, 0);                                         │
│ 44     } else if (pwm_percent < 0) { // Reverse                                                                      │
│ 45         __HAL_TIM_SET_COMPARE(hmotor->pwm_timer, hmotor->channel_fwd, 0);                                         │
│ 46         __HAL_TIM_SET_COMPARE(hmotor->pwm_timer, hmotor->channel_rev, duty_cycle);                                │
│ 47     } else { // Stop                                                                                              │
│ 48         __HAL_TIM_SET_COMPARE(hmotor->pwm_timer, hmotor->channel_fwd, 0);                                         │
│ 49         __HAL_TIM_SET_COMPARE(hmotor->pwm_timer, hmotor->channel_rev, 0);                                         │
│ 50     }                                                                                                             │
│ 51 }                                                                                                                 │
│ 52                                                                                                                   │
│ 53 /**                                                                                                               │
│ 54  * @brief Updates the motor speed based on encoder readings.                                                      │
│ 55  *        Should be called periodically (e.g., in a control loop task).                                           │
│ 56  * @param hmotor Pointer to the Motor_Handle_t structure.                                                         │
│ 57  * @param delta_time_s Time elapsed since the last update in seconds.                                             │
│ 58  */                                                                                                               │
│ 59 void Motor_UpdateSpeed(Motor_Handle_t* hmotor, float delta_time_s) {                                              │
│ 60     if (hmotor == NULL || delta_time_s == 0.0f) return;                                                           │
│ 61                                                                                                                   │
│ 62     int32_t current_counter = __HAL_TIM_GET_COUNTER(hmotor->enc_timer);                                           │
│ 63     int32_t delta_ticks;                                                                                          │
│ 64                                                                                                                   │
│ 65     // Handle 16-bit timer overflow/underflow for delta calculation if period is 65535                            │
│ 66     if (hmotor->enc_timer->Init.Period == 65535) { // Assuming 16-bit timer                                       │
│ 67         delta_ticks = (int16_t)(current_counter - hmotor->enc_prev_counter);                                      │
│ 68     } else { // Assuming 32-bit timer or larger period                                                            │
│ 69         delta_ticks = current_counter - hmotor->enc_prev_counter;                                                 │
│ 70     }                                                                                                             │
│ 71                                                                                                                   │
│ 72     hmotor->enc_prev_counter = current_counter;                                                                   │
│ 73     hmotor->total_ticks += delta_ticks;                                                                           │
│ 74                                                                                                                   │
│ 75     // Calculate speed in rad/s and RPM                                                                           │
│ 76     // (delta_ticks / enc_resolution) gives revolutions                                                           │
│ 77     // (revolutions / delta_time_s) gives revolutions per second                                                  │
│ 78     // (rev/s * 60) gives RPM                                                                                     │
│ 79     // (rev/s * 2*PI) gives rad/s                                                                                 │
│ 80                                                                                                                   │
│ 81     float revolutions_per_second = (float)delta_ticks / (float)hmotor->enc_resolution / delta_time_s;             │
│ 82     hmotor->speed_rpm = revolutions_per_second * 60.0f;                                                           │
│ 83     hmotor->speed_rad_s = revolutions_per_second * 2.0f * 3.1415926535f; // Using PI constant                     │
│ 84 }                                                                                                                 │

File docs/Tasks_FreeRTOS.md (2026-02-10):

# Architecture FreeRTOS pour l'intégration LIDAR + IMU

Ce document décrit la structure à implémenter dans `app_freertos.c` (et les fichiers associés) pour faire tourner les drivers LIDAR et IMU en parallèle.

## 1. Vue d'ensemble des Tâches

| Tâche | Priorité | Stack Size | Périodicité | Rôle |
| :--- | :--- | :--- | :--- | :--- |
| **Task_Lidar** | `osPriorityNormal` | 512 Words | Événementiel (UART RX) | Récupère les données brutes du DMA, parse le protocole X2, détecte les obstacles. |
| **Task_Imu** | `osPriorityBelowNormal` | 256 Words | Périodique (100ms) | Lit l'accéléromètre via I2C, détecte les chocs/tap, calcule l'inclinaison. |
| **defaultTask** | `osPriorityLow` | 128 Words | - | Tâche par défaut (LED Heartbeat ou Idle). |

## 2. Ressources Partagées (Mutex/Sémaphores)

*   **`myI2C1Mutex`** : Essentiel pour protéger l'accès au bus I2C1 (utilisé par l'IMU maintenant, et les capteurs TOF plus tard).
*   **`myUARTMutex`** : Recommandé pour éviter que les `printf` de différentes tâches ne se mélangent sur la console série.

---

## 3. Implémentation dans `app_freertos.c`

### A. Includes et Déclarations

Ajoutez les headers de vos drivers et déclarez les handles.

```c
/* Private includes ----------------------------------------------------------*/
#include "lidar.h"
#include "imu.h"
#include "usart.h" // Pour huart2 (Lidar) et printf
#include "i2c.h"   // Pour hi2c1

/* Private variables ---------------------------------------------------------*/
// Tâches
osThreadId lidiTaskHandle;
osThreadId imuTaskHandle;

// Mutex
osMutexId i2c1MutexHandle;
osMutexId uartMutexHandle;

// Buffer DMA pour le Lidar (Circular Buffer)
#define LIDAR_DMA_BUFFER_SIZE 1024
uint8_t lidar_dma_buffer[LIDAR_DMA_BUFFER_SIZE];
```

### B. Initialisation (`MX_FREERTOS_Init`)

Créez les mutex et les tâches.

```c
void MX_FREERTOS_Init(void) {
  /* Create Mutexes */
  osMutexDef(i2c1Mutex);
  i2c1MutexHandle = osMutexCreate(osMutex(i2c1Mutex));

  osMutexDef(uartMutex);
  uartMutexHandle = osMutexCreate(osMutex(uartMutex));

  /* Create Tasks */
  // Task Lidar
  osThreadDef(lidarTask, StartLidarTask, osPriorityNormal, 0, 512);
  lidiTaskHandle = osThreadCreate(osThread(lidarTask), NULL);

  // Task IMU
  osThreadDef(imuTask, StartImuTask, osPriorityBelowNormal, 0, 256);
  imuTaskHandle = osThreadCreate(osThread(imuTask), NULL);
  
  // defaultTask (déjà existante) ...
}
```

### C. Code de la `Task_Lidar`

Cette tâche doit initialiser le Lidar, lancer la réception DMA, et traiter les données reçues.

**Note sur le DMA :** Pour éviter de bloquer, on lance le DMA en mode circulaire. La tâche surveille la position du pointeur DMA pour traiter les nouveaux octets.

```c
void StartLidarTask(void const * argument)
{
  /* Init Driver Lidar */
  ydlidar_init();
  
  /* Démarrage réception DMA Circulaire sur UART2 */
  HAL_UART_Receive_DMA(&huart2, lidar_dma_buffer, LIDAR_DMA_BUFFER_SIZE);
  
  static uint16_t old_pos = 0;
  
  for(;;)
  {
    // Calcul de la position courante du DMA (NDTR compte à rebours)
    uint16_t pos = LIDAR_DMA_BUFFER_SIZE - __HAL_DMA_GET_COUNTER(huart2.hdmarx);
    
    if (pos != old_pos) {
      if (pos > old_pos) {
        // Pas de bouclage du buffer : on traite de old_pos à pos
        ydlidar_process_data(&lidar_dma_buffer[old_pos], pos - old_pos);
      } else {
        // Bouclage (wrap around) : on traite de old_pos à la fin, puis du début à pos
        ydlidar_process_data(&lidar_dma_buffer[old_pos], LIDAR_DMA_BUFFER_SIZE - old_pos);
        if (pos > 0) {
            ydlidar_process_data(&lidar_dma_buffer[0], pos);
        }
      }
      old_pos = pos;
    }

    // Détection d'objets périodique ou basée sur le scan complet
    // Ici on peut le faire à chaque tour ou utiliser un flag dans le driver
    static uint32_t last_check = 0;
    if (HAL_GetTick() - last_check > 50) { // 20Hz
        LidarObject_t objects[MAX_LIDAR_OBJECTS];
        uint8_t count = 0;
        
        // Protection printf si nécessaire
        // osMutexWait(uartMutexHandle, osWaitForever);
        ydlidar_detect_objects(objects, &count);
        // osMutexRelease(uartMutexHandle);
        
        last_check = HAL_GetTick();
    }

    osDelay(10); // Laisser la main aux autres tâches (10ms polling du buffer)
  }
}
```

### D. Code de la `Task_Imu`

Cette tâche est plus simple : elle lit les capteurs périodiquement. **Il faut absolument protéger l'accès I2C.**

```c
void StartImuTask(void const * argument)
{
  /* Init Driver IMU */
  // On prend le mutex même pour l'init pour être propre (si d'autres tâches I2C existaient)
  osMutexWait(i2c1MutexHandle, osWaitForever);
  if (ADXL343_Init(&hi2c1) != HAL_OK) {
      printf("IMU Init Error\r\n");
  }
  ADXL343_ConfigShock(&hi2c1, 2.5f, 10.0f); // Exemple config choc
  osMutexRelease(i2c1MutexHandle);

  adxl343_axes_t accel_data;

  for(;;)
  {
    osMutexWait(i2c1MutexHandle, osWaitForever);
    
    // 1. Lecture Accélération
    if (ADXL343_ReadAxes(&hi2c1, &accel_data) == HAL_OK) {
        // Conversion en float si besoin pour logique métier
        // float x_g = ADXL343_RawTo_g(accel_data.x);
    }

    // 2. Vérification Choc (Tap)
    if (ADXL343_CheckShock(&hi2c1)) {
        printf("!!! CHOC DETECTE !!!\r\n");
        // Action : Stop moteurs, LED rouge, etc.
    }
    
    osMutexRelease(i2c1MutexHandle);

    osDelay(100); // 10Hz suffisant pour l'inclinomètre. Pour les chocs, réduire le délai ou utiliser les interruptions GPIO.
  }
}
```

---

## 4. Modifications nécessaires dans `main.c`

Assurez-vous que le **Timer de base de temps** (Timebase Source) dans le fichier `.ioc` (CubeMX) est bien réglé sur un autre Timer que Systick (ex: `TIM1` ou `TIM6`), car FreeRTOS utilise Systick.
*   Si vous avez généré le code avec CubeMX en activant FreeRTOS, cela devrait être déjà fait (`HAL_InitTick` utilise TIM1 dans votre code actuel `stm32g4xx_hal_timebase_tim.c`).

## 5. Prochaines étapes

1.  Copier les prototypes et déclarations dans `app_freertos.c`.
2.  Implémenter `StartLidarTask` et `StartImuTask`.
3.  Compiler et flasher.
4.  Vérifier via le port série (Virtual Com Port) que :
    *   Le Lidar affiche les objets détectés.
    *   L'IMU réagit aux mouvements/chocs.
    *   Les deux messages s'affichent sans bloquer le système.

```

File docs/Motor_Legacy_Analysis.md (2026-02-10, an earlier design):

# Analyse Comparative : Driver Moteur Legacy vs Cible

**Date :** 8 Décembre 2025
**Source Legacy :** `@raf/firmware/.../moteur.c`
**Cible :** Nouveau driver modulaire `motor_driver`

Ce document analyse le code moteur de l'année précédente pour en extraire les bonnes idées et identifier les pièges à éviter dans la nouvelle implémentation.

---

## 1. Architecture & Modularité

### Code Legacy (`moteur.c`)
*   **Approche :** "Tout-en-un" (Monolithique). Le fichier contient la gestion bas niveau (PWM/Encodeur), la logique métier (Modes Souris/Prédateur), et même l'algorithme PID.
*   **Dépendances :** Fortement couplé aux variables globales `htim1`, `htim3`, `htim4`. Les fonctions appellent directement les handles globaux.
*   **Duplication :** Fonctions séparées pour `forward_r`, `forward_l`, `reverse_r`, `reverse_l`.
    *   *Critique :* Difficile à maintenir. Si on change un timer, il faut changer 4 fonctions.

### Architecture Cible (`motor_driver`)
*   **Approche :** Orientée Objet (Struct `Motor_Handle_t`).
*   **Modularité :** Le driver ne gère QUE le moteur (PWM + Encodeur). Il ne connait pas le PID, ni la stratégie (Souris/Prédateur).
*   **Abstraction :** Une seule fonction `Motor_SetSpeed(handle, percent)` gère le sens (Fwd/Rev) et le moteur (Gauche/Droit) via la configuration stockée dans la structure.

---

## 2. Qualité du Code (PWM & Encodeurs)

### Code Legacy
*   **Contrôle PWM :** Utilise `__HAL_TIM_SET_COMPARE` et `HAL_TIMEx_PWMN_Start/Stop`.
    *   *Observation :* Utilise les sorties complémentaires (CHxN) du Timer 1. C'est spécifique aux drivers moteur "H-Bridge" avancés.
    *   *Bug Potentiel :* Dans `reverse_r`, on voit des lignes commentées et un mélange Start/Stop qui suggère que la mise au point a été laborieuse.
*   **Calcul Vitesse (`calculate_motor_speed`) :**
    *   Utilise des variables `static` locales pour mémoriser la position précédente.
    *   *Problème :* Cette fonction n'est pas réentrante. Si appelée pour LEFT puis RIGHT, les variables statiques `last_position_motorX` sont séparées par des `if`, ce qui est fragile.
    *   *Gestion Overflow :* La soustraction `current - last` est faite sur des `int16_t`. C'est **correct** pour gérer le débordement naturel des timers 16 bits.

### Architecture Cible
*   **Contrôle PWM :** Adapté à notre hardware actuel (ZXBM5210 sur TIM3). Pas de sorties complémentaires "N" utilisées dans le projet actuel `Test_Motor`.
*   **Calcul Vitesse :** Stockera `prev_counter` dans la structure `Motor_Handle_t`, rendant la fonction de calcul parfaitement réentrante et thread-safe.

---

## 3. Gestion du Temps & FreeRTOS

### Code Legacy
*   **Mélange :** Utilise `HAL_Delay` (bloquant) dans certaines boucles, et `vTaskDelay` (FreeRTOS) dans d'autres (`motorcontrol_souris`).
*   **Affichage :** Utilise beaucoup de `printf` dans les fonctions de contrôle.
    *   *Impact :* Ralentit considérablement la boucle de contrôle, ce qui est désastreux pour un PID stable.

### Architecture Cible
*   **Strictement Non-Bloquant :** Aucune fonction `Delay` ni `printf` dans le driver.
*   **Périodicité :** Le calcul de vitesse `Motor_UpdateSpeed` sera appelé par une tâche cyclique précise (`Task_ControlLoop`) et prendra `delta_time` en argument pour être indépendant de la fréquence d'appel.

---

## 4. Asservissement (PID)

### Code Legacy
*   **Implémentation :** Fonction `compute_pid` standard.
*   **Problème PID :** Le terme intégral `integral_error` n'est pas borné (pas d'Anti-Windup).
    *   *Risque :* Si le moteur est bloqué, l'intégrale explose et le moteur part à fond dès qu'il est débloqué.

### Architecture Cible
*   Le PID sera sorti du driver et mis dans `Core/App/pid_controller.c`.
*   Ajout impératif d'un **Anti-Windup** (limitation de la somme intégrale).

---

## 5. Recommandations pour le Nouveau Driver

1.  **Ne pas copier-coller** le code legacy. L'approche est trop différente.
2.  **S'inspirer** de la gestion du débordement 16-bit des encodeurs (c'était correct).
3.  **Ignorer** la gestion spécifique `TIM1_CH1N` (complémentaire) sauf si notre hardware l'exige (le projet actuel utilise TIM3 qui n'a pas de canaux N sortis sur les pins standards de la même manière pour ce driver).
4.  **Séparer** totalement la logique de contrôle (Avancer, Reculer) de la logique de stratégie (Souris, Prédateur).

**Conclusion :** Le driver legacy est un code de prototypage "rapide". Notre objectif est un code de production "industriel".

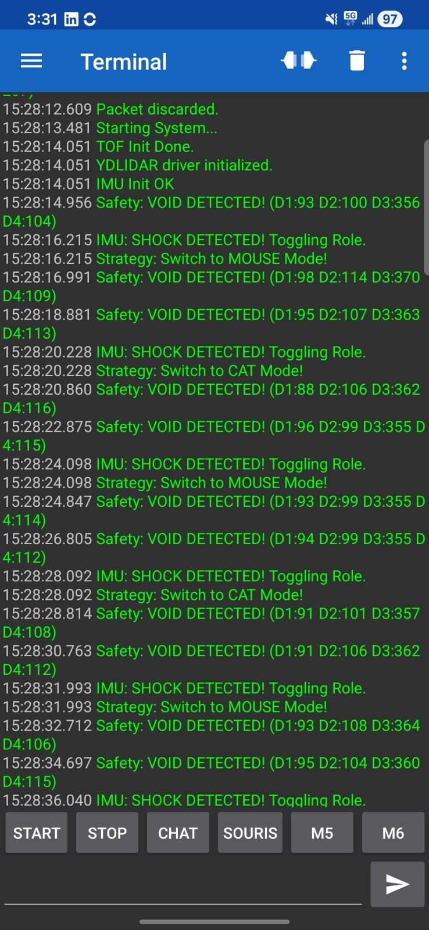
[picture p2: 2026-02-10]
docs/output_terminal.jpeg

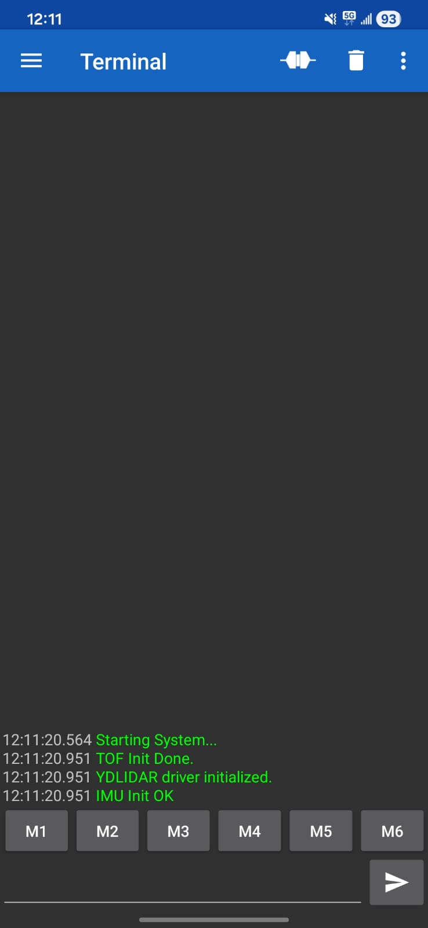
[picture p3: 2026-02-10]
docs/terminal_bt1.jpeg

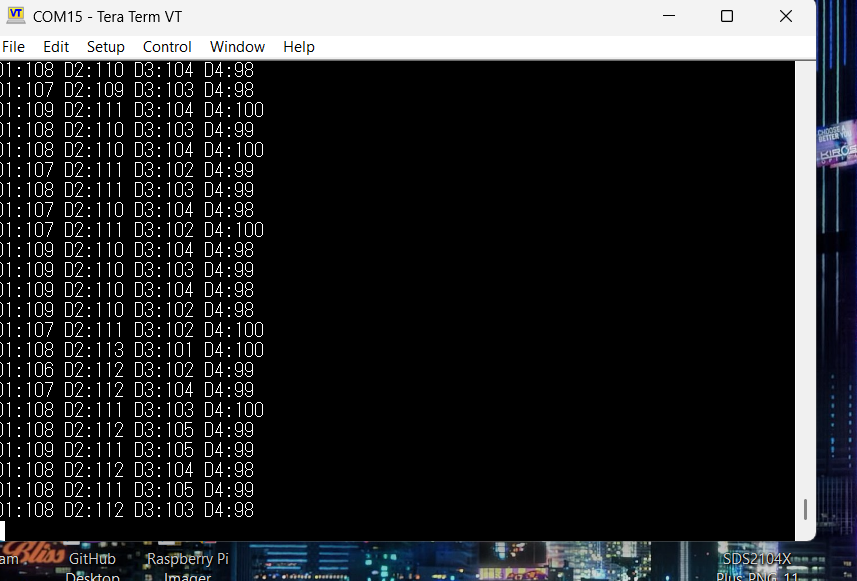
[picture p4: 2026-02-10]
docs/dist_min_tof.png

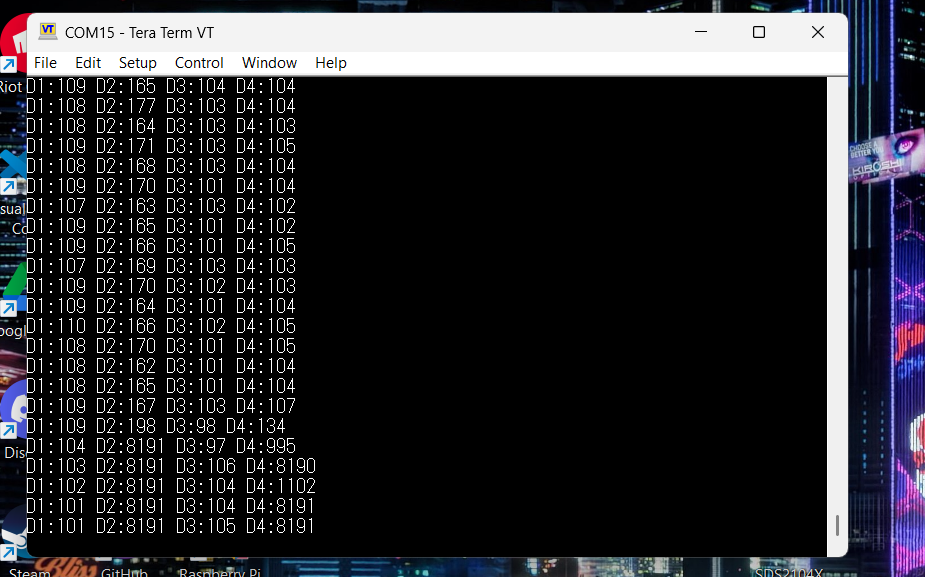
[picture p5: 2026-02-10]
docs/dist_max_tof.png

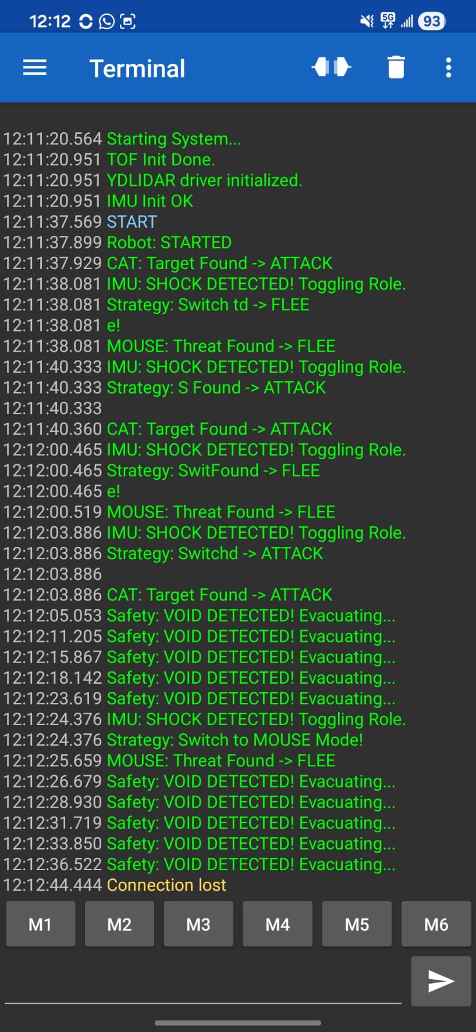
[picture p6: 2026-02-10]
docs/terminal_bt2.jpeg

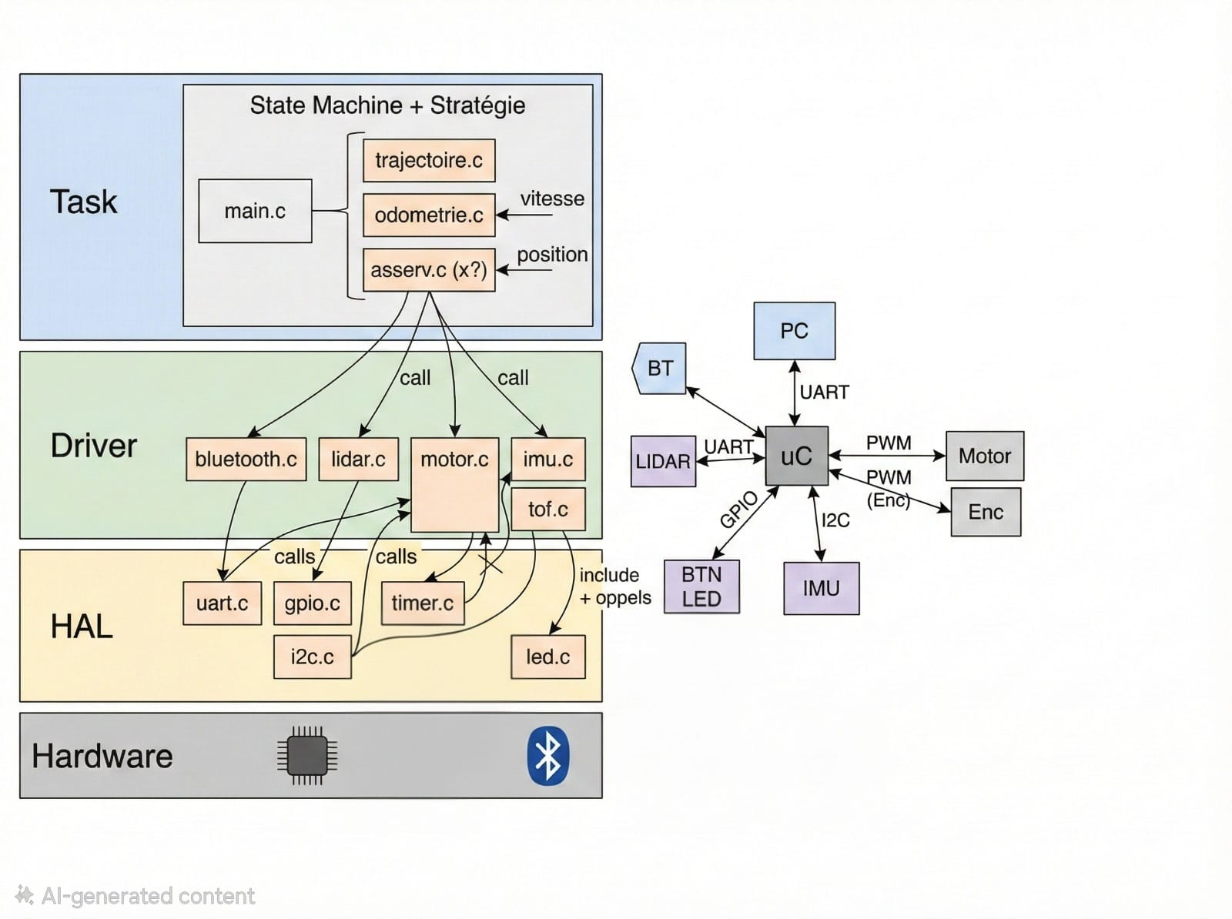
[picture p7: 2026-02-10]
docs/structure.jpeg

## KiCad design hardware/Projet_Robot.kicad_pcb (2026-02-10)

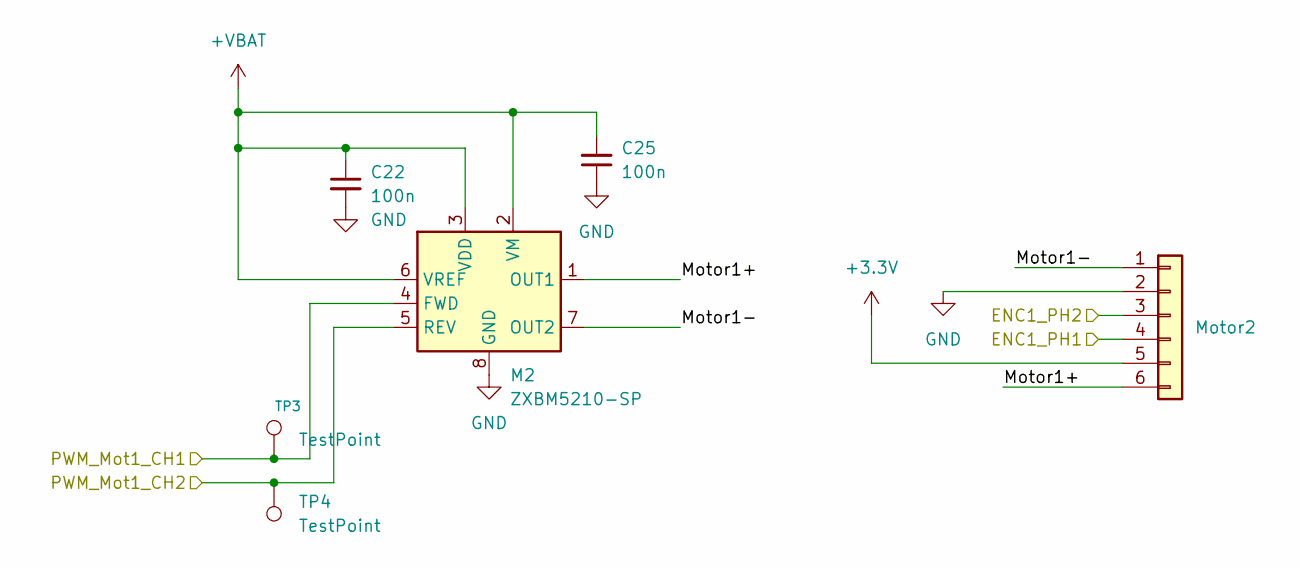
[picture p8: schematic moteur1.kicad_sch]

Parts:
C22, C25: 100n; C_0402_1005Metric
M2: ZXBM5210-SP; Diodes_SO-8EP
Motor2: Conn_01x06; JST_XH_S6B-XH-A_1x06_P2.50mm_Horizontal
TP3, TP4: TestPoint; TestPoint_Pad_D1.5mm

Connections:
+3.3V: Motor2.5; also elsewhere on the board
+VBAT: C22.1, C25.2, M2.2 (VM), M2.3 (VDD), M2.6 (VREF); also elsewhere on the board
/Moteur2/ENC1_PH1: Motor2.4; also elsewhere on the board
/Moteur2/ENC1_PH2: Motor2.3; also elsewhere on the board
/Moteur2/Motor1+: M2.1 (OUT1), Motor2.6
/Moteur2/Motor1-: M2.7 (OUT2), Motor2.1
/Moteur2/PWM_Mot1_CH1: M2.4 (FWD), TP3.1; also elsewhere on the board
GND: C22.2, C25.1, M2.8 (GND), M2.9 (GND), Motor2.2; also elsewhere on the board

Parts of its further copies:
C23, C24: 100n; C_0402_1005Metric
M1: ZXBM5210-SP; Diodes_SO-8EP
Motor1: Conn_01x06; JST_XH_S6B-XH-A_1x06_P2.50mm_Horizontal
TP1, TP2: TestPoint; TestPoint_Pad_D1.5mm

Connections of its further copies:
+3.3V: Motor1.5; also elsewhere on the board
+VBAT: C23.1, C24.2, M1.2 (VM), M1.3 (VDD), M1.6 (VREF); also elsewhere on the board
/Moteur1/ENC1_PH1: Motor1.4; also elsewhere on the board
/Moteur1/ENC1_PH2: Motor1.3; also elsewhere on the board
/Moteur1/Motor1+: M1.1 (OUT1), Motor1.6
/Moteur1/Motor1-: M1.7 (OUT2), Motor1.1
/Moteur1/PWM_Mot1_CH1: M1.4 (FWD), TP1.1; also elsewhere on the board
GND: C23.2, C24.1, M1.8 (GND), M1.9 (GND), Motor1.2; also elsewhere on the board

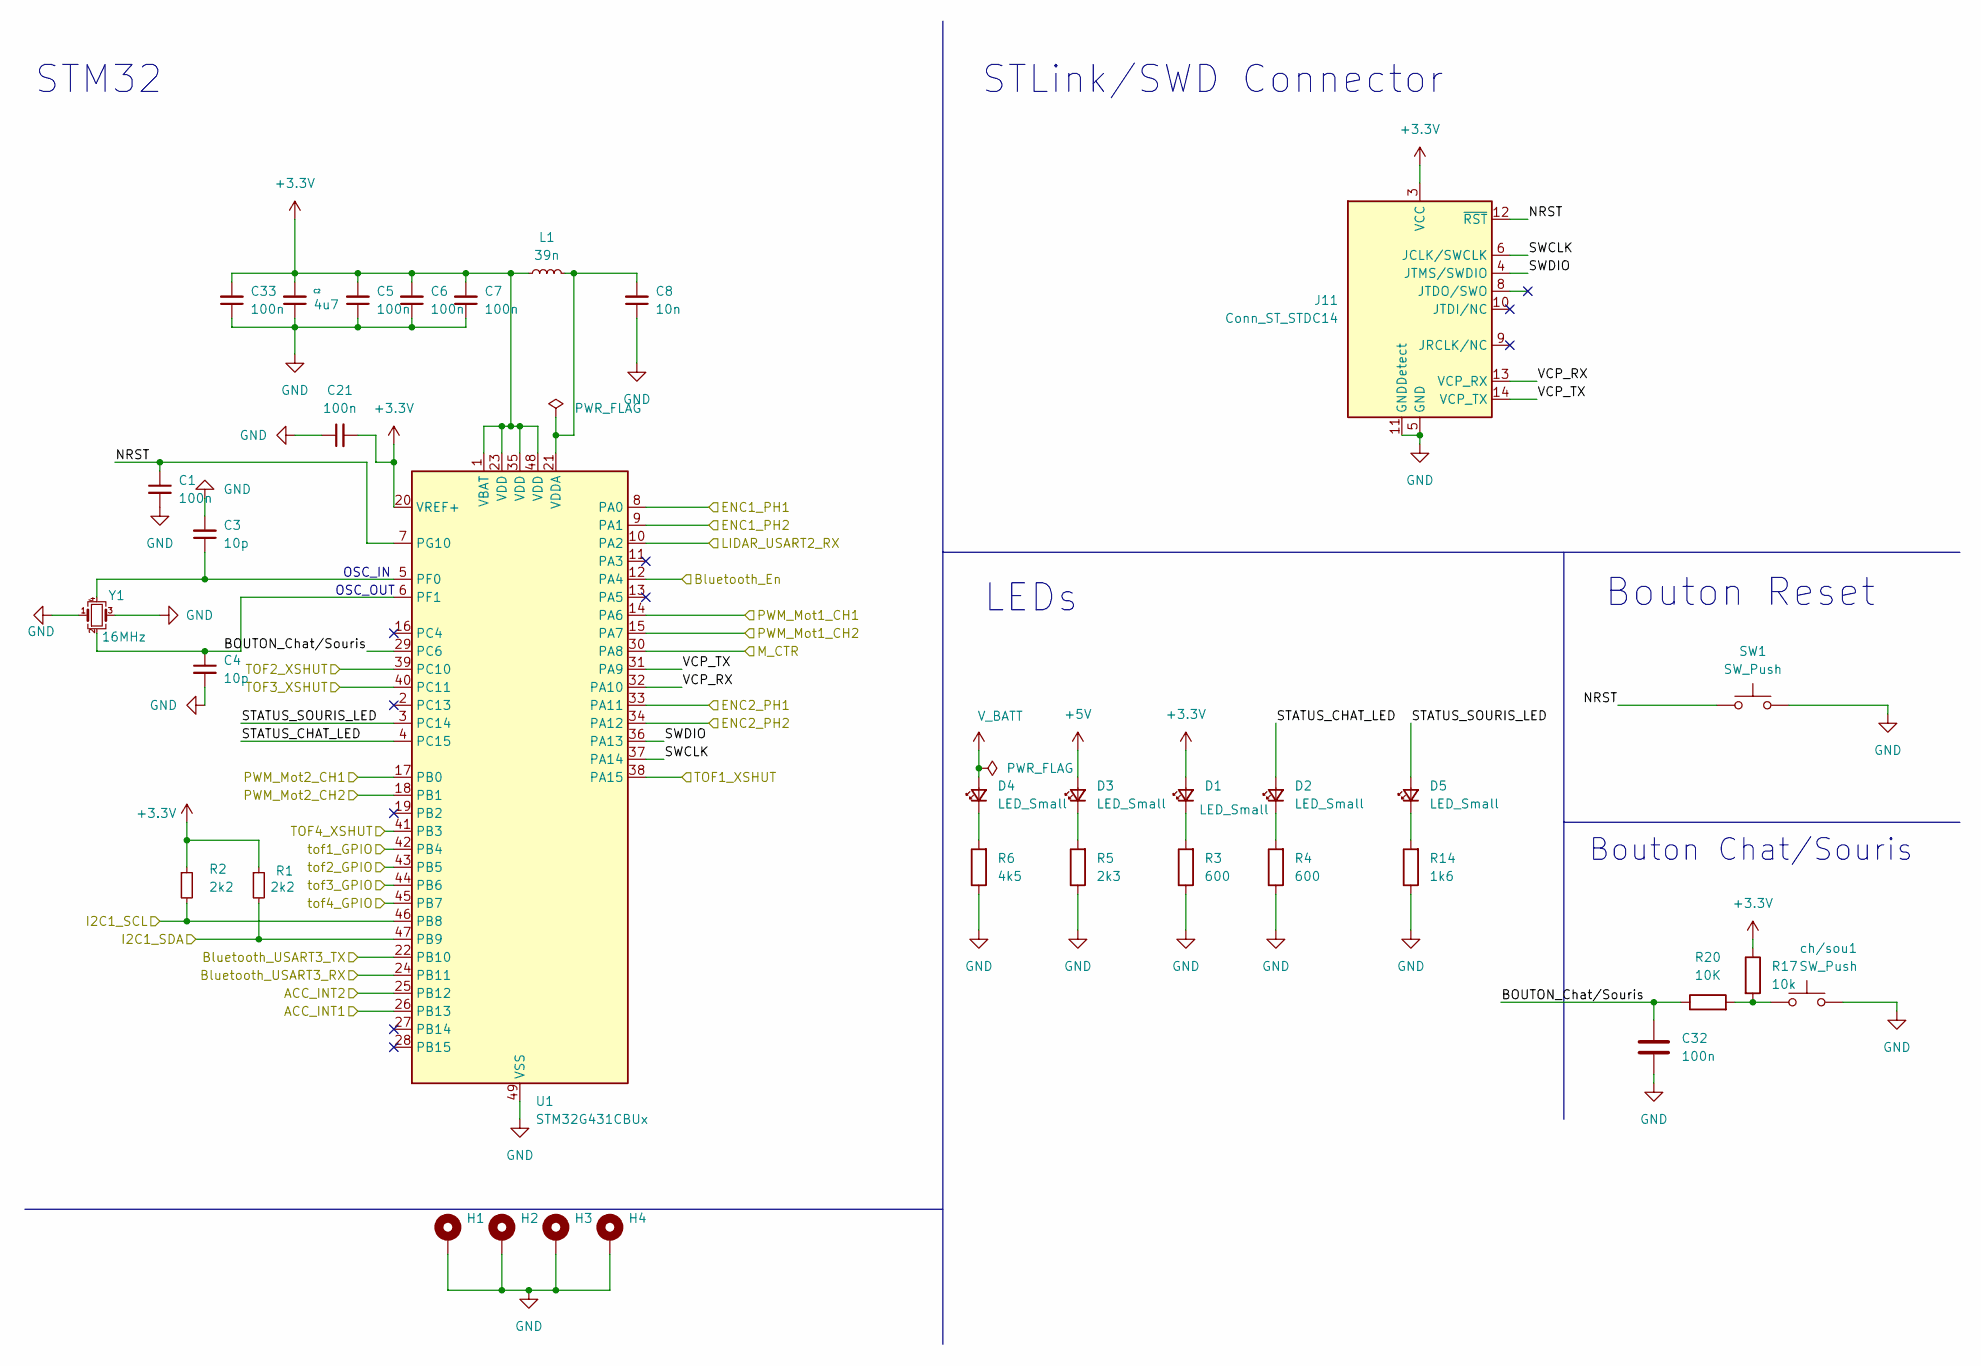
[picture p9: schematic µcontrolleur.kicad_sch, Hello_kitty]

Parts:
C1, C5, C6, C7, C21, C32, C33: 100n; C_0402_1005Metric
C2: 4u7; C_0603_1608Metric
C3, C4: 10p; C_0402_1005Metric
C8: 10n; C_0603_1608Metric
D1, D2, D3, D4, D5: LED_Small; LED_0603_1608Metric
H1, H2, H3, H4: MountingHole_Pad; MountingHole_3.2mm_M3_Pad_Via
J11: Conn_ST_STDC14; PinHeader_2x07_P1.27mm_Vertical_SMD
L1: 39n; L_0603_1608Metric
R1, R2: 2k2; R_0603_1608Metric
R3, R4: 600; R_0603_1608Metric
R5: 2k3; R_0603_1608Metric
R6: 4k5; R_0603_1608Metric
R14: 1k6; R_0603_1608Metric
R17: 10k; R_0603_1608Metric
R20: 10K; R_0603_1608Metric
SW1: SW_Push; SW Push 1P1T NO 6x6mm H9.5mm
U1: STM32G431CBUx; QFN-48-1EP_7x7mm_P0.5mm_EP5.6x5.6mm
Y1: 16MHz; Crystal_SMD_EuroQuartz_MT-4Pin_3.2x2.5mm
ch/sou1: SW_Push; SW Push 1P1T NO 6x6mm H9.5mm

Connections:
+3.3V: C2.2, C5.2, C6.2, C7.2, C21.2, C33.2, D1.2 (A), J11.3 (VCC), L1.1, R1.1, R2.1, R17.1, U1.1 (VBAT), U1.20 (VREF+), U1.23 (VDD), U1.35 (VDD), U1.48 (VDD); also elsewhere on the board
+5V: D3.2 (A); also elsewhere on the board
/Capteurs/ACC_INT1: U1.26 (PB13); also elsewhere on the board
/Capteurs/ACC_INT2: U1.25 (PB12); also elsewhere on the board
/Capteurs/Bluetooth_En: U1.12 (PA4); also elsewhere on the board
/Capteurs/Bluetooth_USART3_RX: U1.24 (PB11); also elsewhere on the board
/Capteurs/Bluetooth_USART3_TX: U1.22 (PB10); also elsewhere on the board
/Capteurs/I2C1_SCL: R2.2, U1.46 (PB8); also elsewhere on the board
/Capteurs/I2C1_SDA: R1.2, U1.47 (PB9); also elsewhere on the board
/Capteurs/LIDAR_USART2_RX: U1.10 (PA2); also elsewhere on the board
/Capteurs/M_CTR: U1.30 (PA8); also elsewhere on the board
/Capteurs/TOF1_XSHUT: U1.38 (PA15); also elsewhere on the board
/Capteurs/TOF2_XSHUT: U1.39 (PC10); also elsewhere on the board
/Capteurs/TOF3_XSHUT: U1.40 (PC11); also elsewhere on the board
/Capteurs/TOF4_XSHUT: U1.41 (PB3); also elsewhere on the board
/Capteurs/tof1_GPIO: U1.42 (PB4); also elsewhere on the board
/Capteurs/tof2_GPIO: U1.43 (PB5); also elsewhere on the board
/Capteurs/tof3_GPIO: U1.44 (PB6); also elsewhere on the board
/Capteurs/tof4_GPIO: U1.45 (PB7); also elsewhere on the board
/Moteur1/ENC1_PH1: U1.8 (PA0); also elsewhere on the board
/Moteur1/ENC1_PH2: U1.9 (PA1); also elsewhere on the board
/Moteur1/PWM_Mot1_CH1: U1.14 (PA6); also elsewhere on the board
/Moteur2/ENC1_PH1: U1.33 (PA11); also elsewhere on the board
/Moteur2/ENC1_PH2: U1.34 (PA12); also elsewhere on the board
/Moteur2/PWM_Mot1_CH1: U1.17 (PB0); also elsewhere on the board
/µcontrolleur/BOUTON_Chat/Souris: C32.1, R20.1, U1.29 (PC6)
/µcontrolleur/NRST: C1.1, J11.12 (~RST), SW1.1, U1.7 (PG10)
/µcontrolleur/STATUS_CHAT_LED: D2.2 (A), U1.4 (PC15)
/µcontrolleur/STATUS_SOURIS_LED: D5.2 (A), U1.3 (PC14)
/µcontrolleur/SWCLK: J11.6 (JCLK/SWCLK), U1.37 (PA14)
/µcontrolleur/SWDIO: J11.4 (JTMS/SWDIO), U1.36 (PA13)
/µcontrolleur/VCP_RX: J11.13 (VCP_RX), U1.32 (PA10)
/µcontrolleur/VCP_TX: J11.14 (VCP_TX), U1.31 (PA9)
GND: C1.2, C2.1, C3.2, C4.2, C5.1, C6.1, C7.1, C8.1, C21.1, C32.2, C33.1, H1.1, H2.1, H3.1, H4.1, J11.5 (GND), J11.7 (GND), J11.11 (GNDDetect), R3.1, R4.1, R5.1, R6.1, R14.1, SW1.2, U1.49 (VSS), Y1.1, Y1.3, ch/sou1.2; also elsewhere on the board
unnamed: D1.1 (K), R3.2
unnamed: D2.1 (K), R4.2
unnamed: D3.1 (K), R5.2
unnamed: D4.1 (K), R6.2
unnamed: D5.1 (K), R14.2
unnamed: R17.2, R20.2, ch/sou1.1
unnamed: C3.1, U1.5 (PF0), Y1.4
unnamed: C4.1, U1.6 (PF1), Y1.2
unnamed: C8.2, L1.2, U1.21 (VDDA)
V_BATT: D4.2 (A)

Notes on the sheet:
OSC_OUT
STM32
LEDs
STLink/SWD Connector
Bouton Chat/Souris
Bouton Reset
OSC_IN

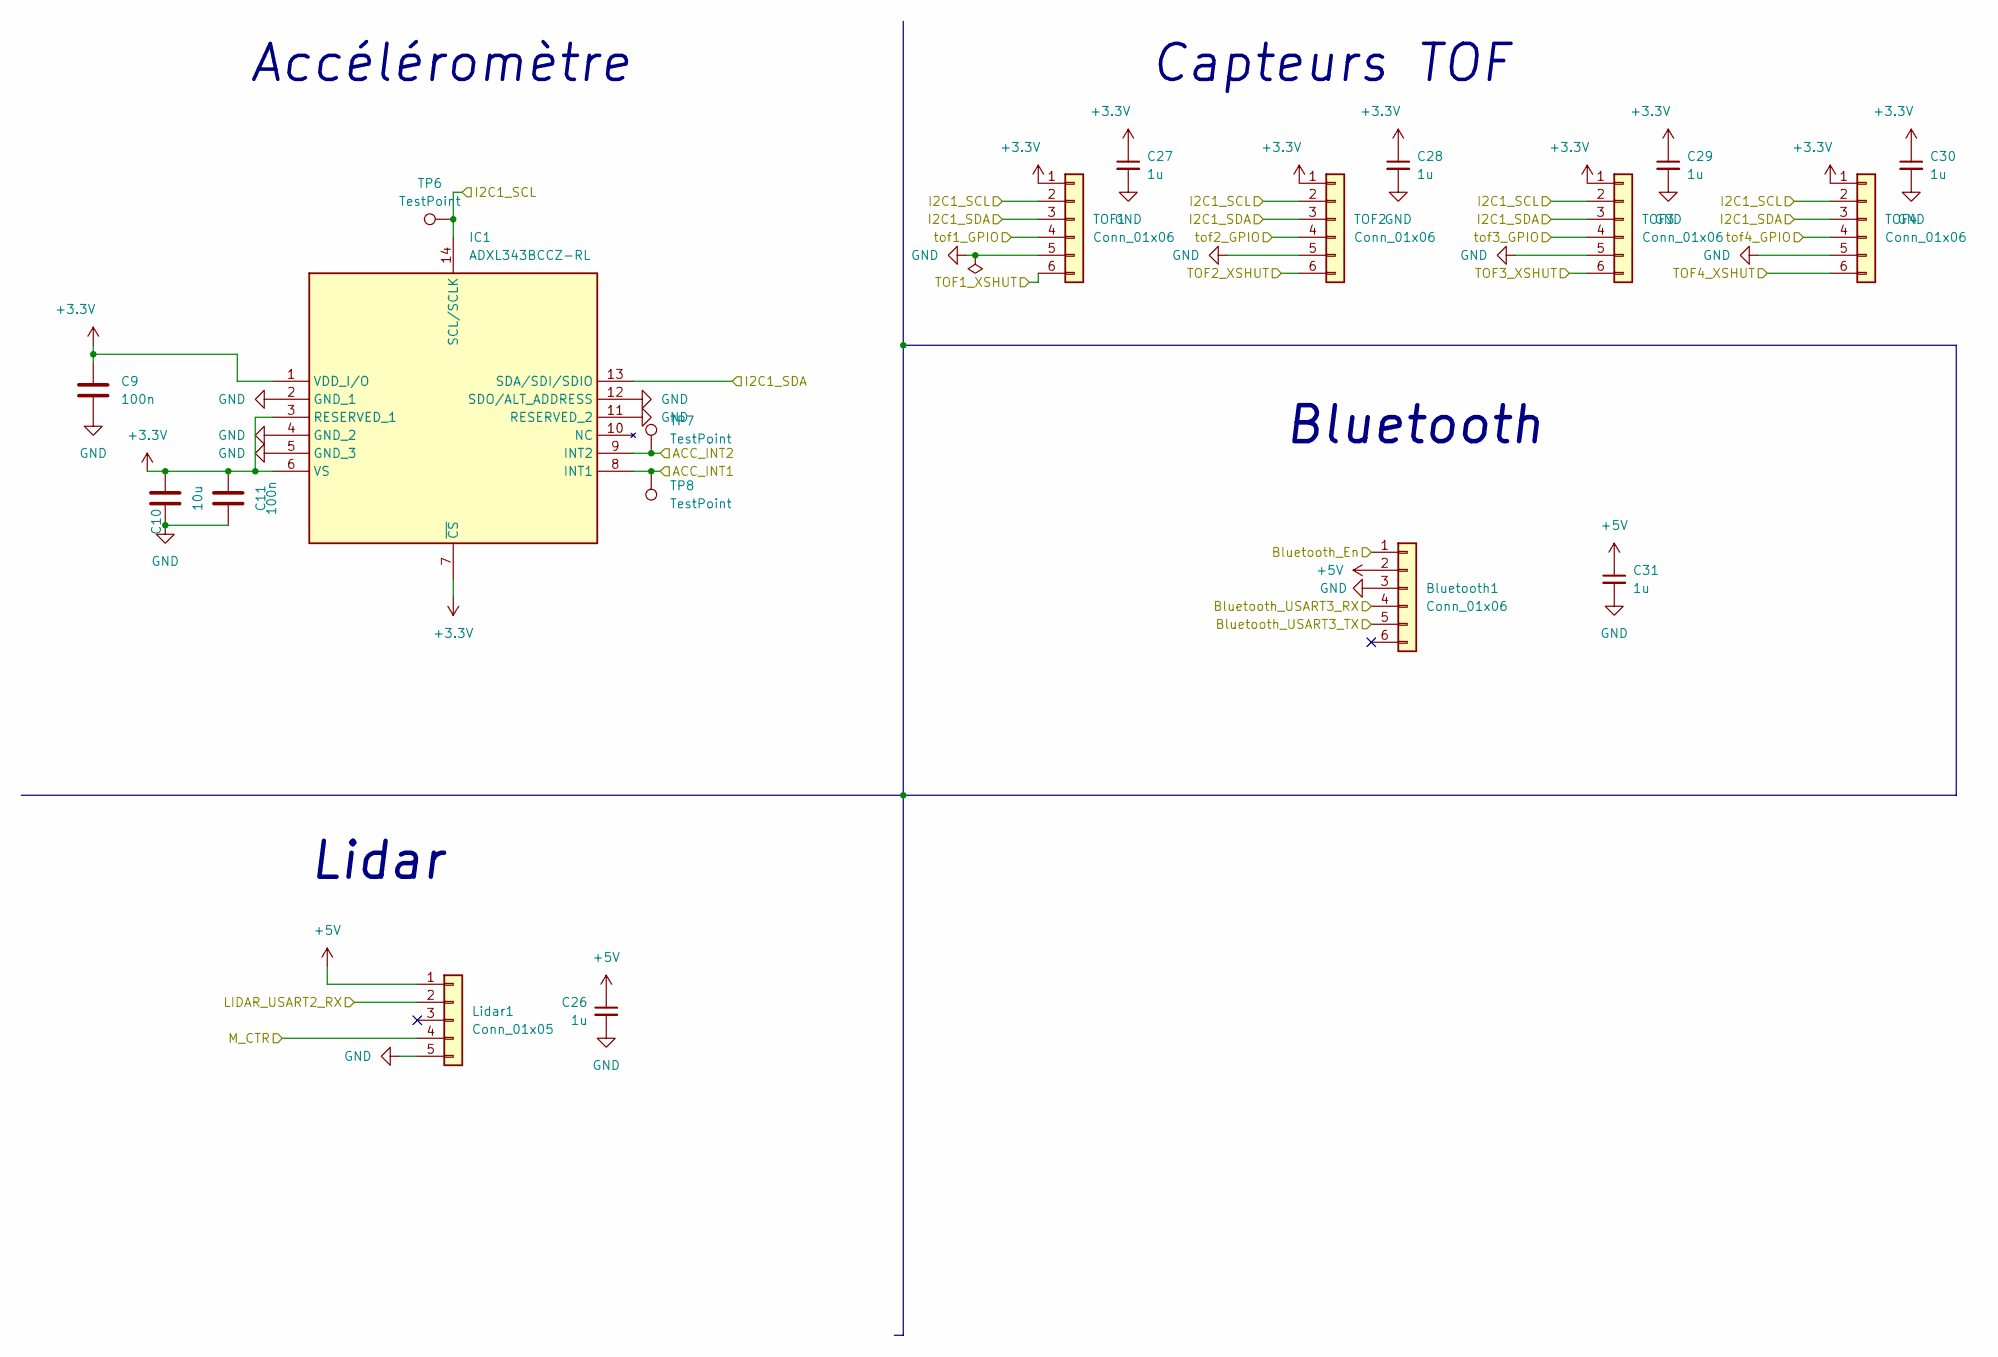
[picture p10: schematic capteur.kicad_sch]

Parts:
Bluetooth1: Conn_01x06; PinSocket_1x06_P2.54mm_Vertical
C9, C11: 100n; C_0402_1005Metric
C10: 10u; C_0603_1608Metric
C26, C27, C28, C29, C30, C31: 1u; C_0603_1608Metric
IC1: ADXL343BCCZ-RL; LGA-14_3x5mm_P0.8mm_LayoutBorder1x6y; Mouser Part Number 584-ADXL343BCCZ-R
Lidar1: Conn_01x05; JST_XH_B5B-XH-A_1x05_P2.50mm_Vertical
TOF1, TOF2, TOF3, TOF4: Conn_01x06; PinSocket_1x06_P2.54mm_Vertical
TP6, TP7, TP8: TestPoint; TestPoint_Pad_D1.5mm

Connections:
+3.3V: C9.2, C10.2, C11.2, C27.1, C28.1, C29.1, C30.1, IC1.1 (VDD_I/O), IC1.3 (RESERVED_1), IC1.6 (VS), IC1.7 (~CS), TOF1.1, TOF2.1, TOF3.1, TOF4.1; also elsewhere on the board
+5V: Bluetooth1.2, C26.1, C31.1, Lidar1.1; also elsewhere on the board
/Capteurs/ACC_INT1: IC1.8 (INT1), TP8.1; also elsewhere on the board
/Capteurs/ACC_INT2: IC1.9 (INT2), TP7.1; also elsewhere on the board
/Capteurs/Bluetooth_En: Bluetooth1.1; also elsewhere on the board
/Capteurs/Bluetooth_USART3_RX: Bluetooth1.4; also elsewhere on the board
/Capteurs/Bluetooth_USART3_TX: Bluetooth1.5; also elsewhere on the board
/Capteurs/I2C1_SCL: IC1.14 (SCL/SCLK), TOF1.2, TOF2.2, TOF3.2, TOF4.2, TP6.1; also elsewhere on the board
/Capteurs/I2C1_SDA: IC1.13 (SDA/SDI/SDIO), TOF1.3, TOF2.3, TOF3.3, TOF4.3; also elsewhere on the board
/Capteurs/LIDAR_USART2_RX: Lidar1.2; also elsewhere on the board
/Capteurs/M_CTR: Lidar1.4; also elsewhere on the board
/Capteurs/TOF1_XSHUT: TOF1.6; also elsewhere on the board
/Capteurs/TOF2_XSHUT: TOF2.6; also elsewhere on the board
/Capteurs/TOF3_XSHUT: TOF3.6; also elsewhere on the board
/Capteurs/TOF4_XSHUT: TOF4.6; also elsewhere on the board
/Capteurs/tof1_GPIO: TOF1.4; also elsewhere on the board
/Capteurs/tof2_GPIO: TOF2.4; also elsewhere on the board
/Capteurs/tof3_GPIO: TOF3.4; also elsewhere on the board
/Capteurs/tof4_GPIO: TOF4.4; also elsewhere on the board
GND: Bluetooth1.3, C9.1, C10.1, C11.1, C26.2, C27.2, C28.2, C29.2, C30.2, C31.2, IC1.2 (GND_1), IC1.4 (GND_2), IC1.5 (GND_3), IC1.11 (RESERVED_2), IC1.12 (SDO/ALT_ADDRESS), Lidar1.5, TOF1.5, TOF2.5, TOF3.5, TOF4.5; also elsewhere on the board

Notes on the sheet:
Lidar
Bluetooth
Accéléromètre
Capteurs TOF

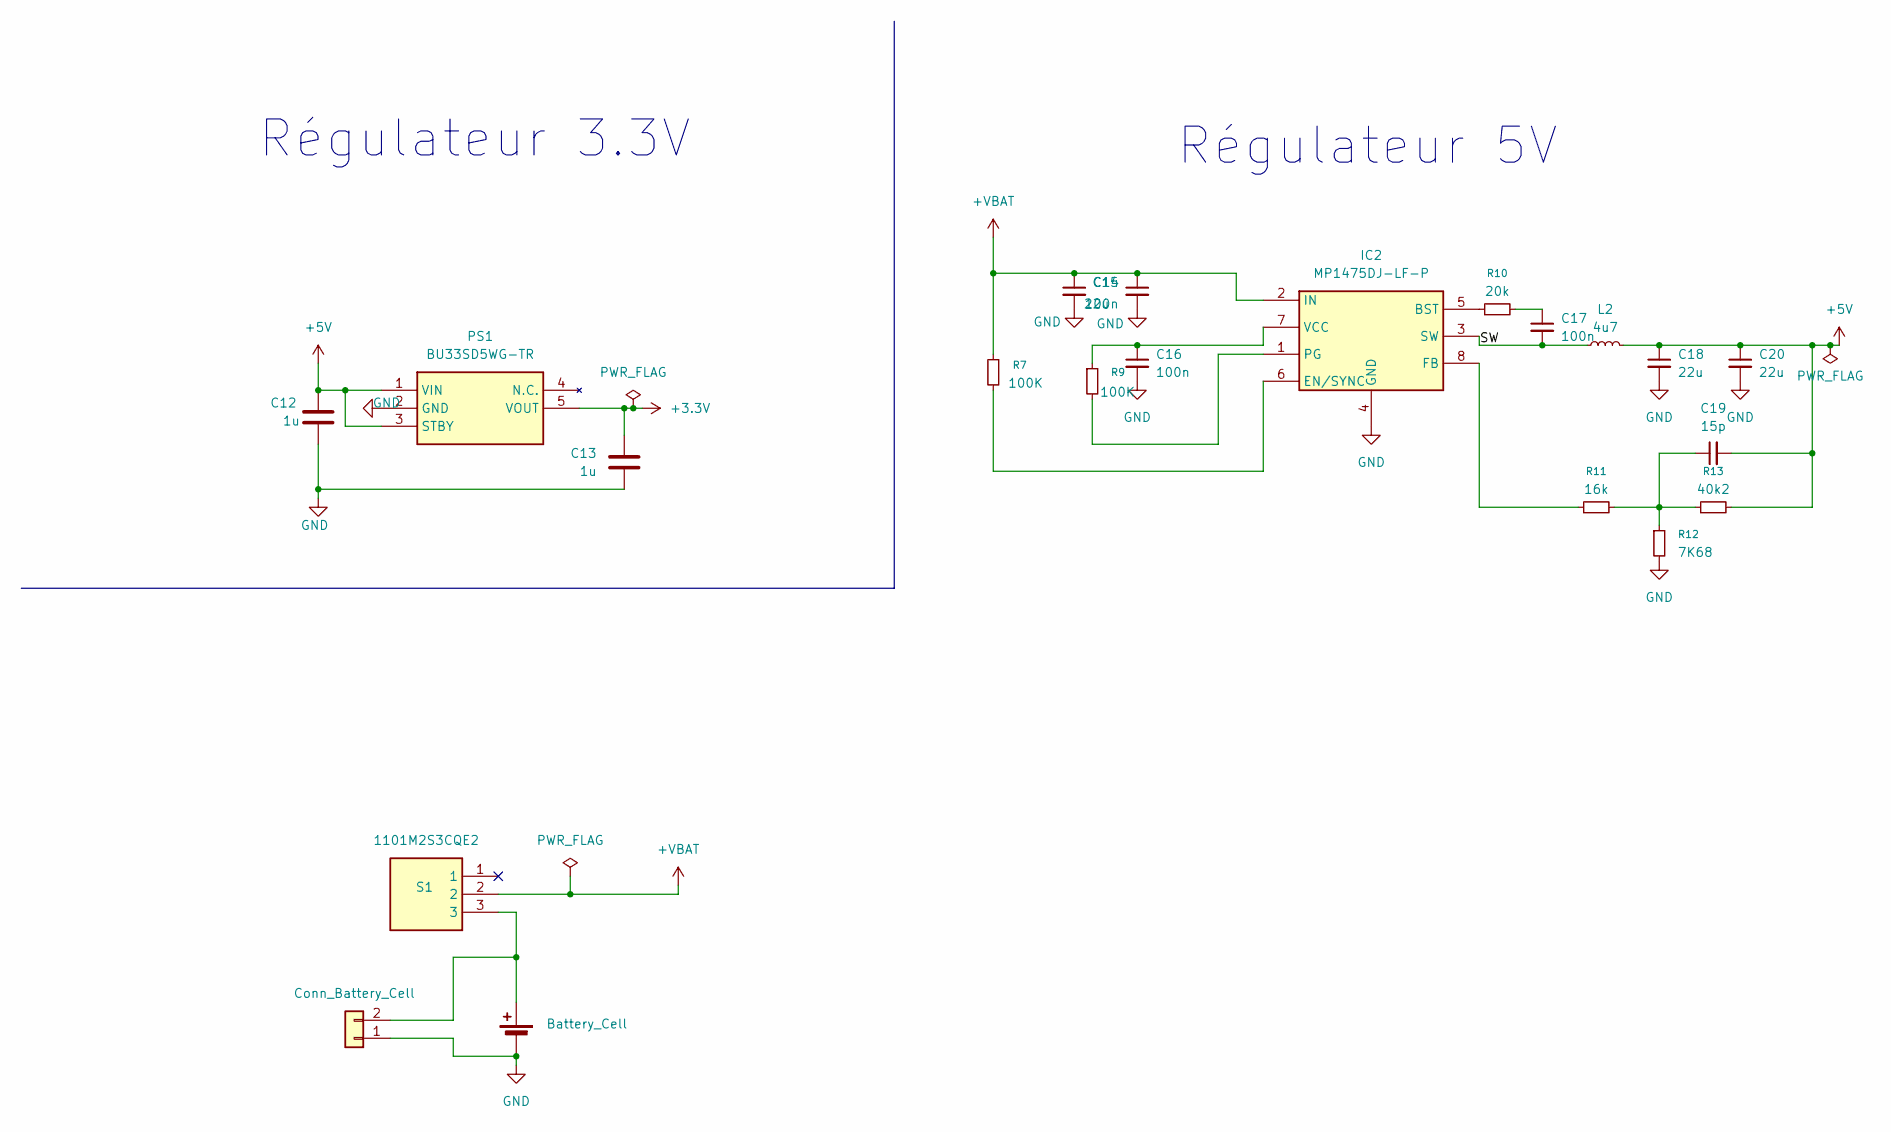
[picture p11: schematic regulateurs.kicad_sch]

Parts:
BT1: Battery_Cell; JST_XH_S2B-XH-A-1_1x02_P2.50mm_Horizontal
C12, C13: 1u; C_0603_1608Metric
C14, C18, C20: 22u; C_0805_2012Metric
C15, C16, C17: 100n; C_0402_1005Metric
C19: 15p; C_0402_1005Metric
IC2: MP1475DJ-LF-P; TSOT-23-8_HandSoldering; Manufacturer_Part_Number MP1475DJ-LF-P
J1: Conn_Battery_Cell; JST_EH_B2B-EH-A_1x02_P2.50mm_Vertical
L2: 4u7; L_APV_ANR5040
PS1: BU33SD5WG-TR; TSOP-5_1.65x3.05mm_P0.95mm; Manufacturer_Part_Number BU33SD5WG-TR; Mouser Part Number 755-BU33SD5WG-TR
R7, R9: 100K; R_0603_1608Metric
R10: 20k; R_0603_1608Metric
R11: 16k; R_0603_1608Metric
R12: 7K68; R_0603_1608Metric
R13: 40k2; R_0603_1608Metric
S1: 1101M2S3CQE2; 1101M2S3QE2; Manufacturer_Part_Number 1101M2S3CQE2

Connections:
+3.3V: C13.2, PS1.5 (VOUT); also elsewhere on the board
+5V: C12.1, C18.1, C19.2, C20.1, L2.2, PS1.1 (VIN), PS1.3 (STBY), R13.2; also elsewhere on the board
+VBAT: C14.1, C15.1, IC2.2 (IN), R7.1, S1.2; also elsewhere on the board
/Régulateurs/SW: C17.2, IC2.3 (SW), L2.1
GND: C12.2, C13.1, C14.2, C15.2, C16.2, C18.2, C20.2, IC2.4 (GND), J1.1, PS1.2 (GND), R12.2; also elsewhere on the board
unnamed: C17.1, R10.2
unnamed: C19.1, R11.2, R12.1, R13.1
unnamed: IC2.5 (BST), R10.1
unnamed: IC2.6 (EN/SYNC), R7.2
unnamed: IC2.8 (FB), R11.1
unnamed: IC2.1 (PG), R9.2
unnamed: C16.1, IC2.7 (VCC), R9.1
unnamed: BT1.1 (+), J1.2, S1.3

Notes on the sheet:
Régulateur 5V
Régulateur 3.3V

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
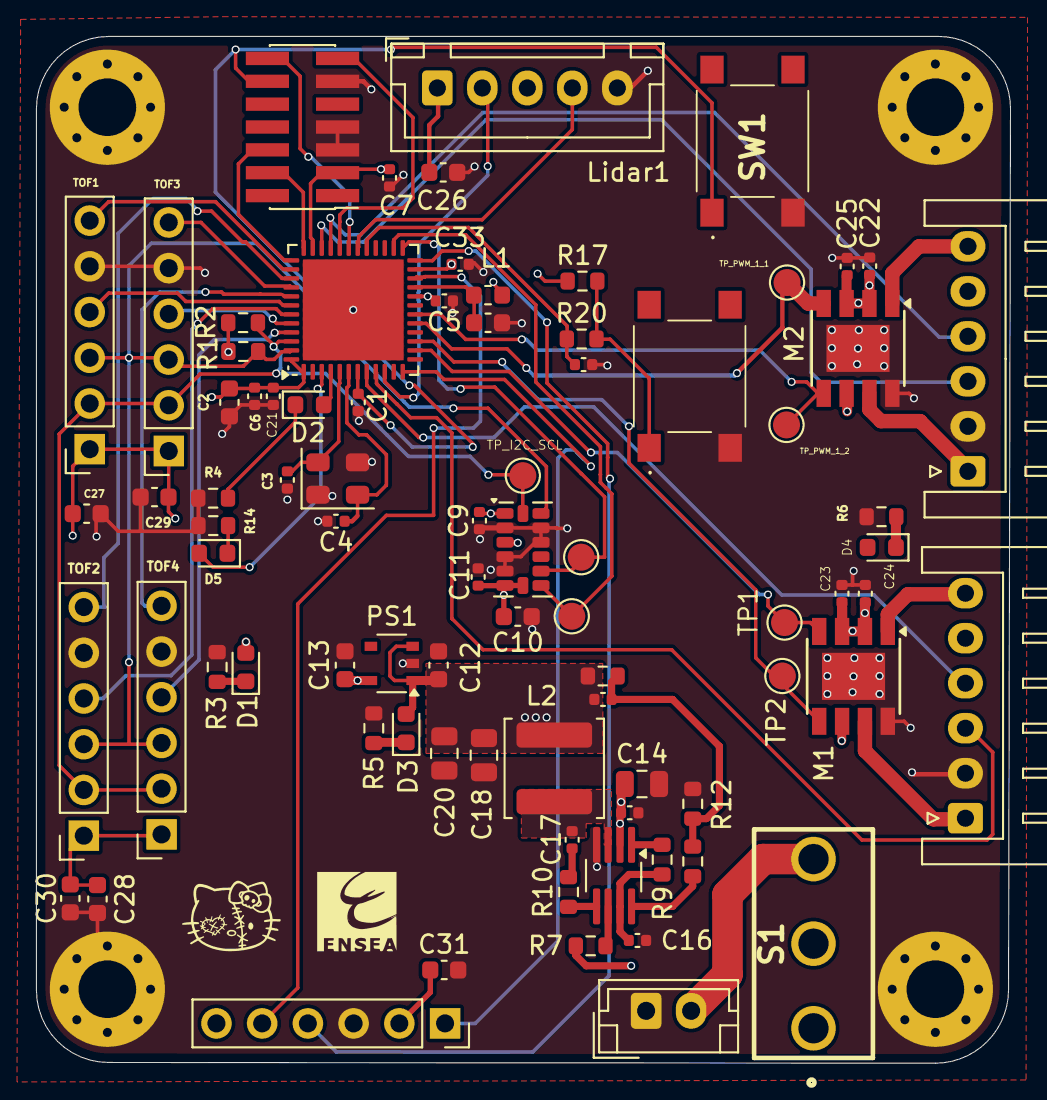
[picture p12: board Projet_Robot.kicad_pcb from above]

Board: 4 copper layers, 54.1 x 57.0 mm, 87 parts (0 on the bottom side), 59 nets.

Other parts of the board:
HelloKitty: L; logo hello
TP_PWM_1_2: TestPoint; TestPoint_Pad_D1.5mm

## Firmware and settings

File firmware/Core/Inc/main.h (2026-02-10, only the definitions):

#define STATUS_SOURIS_LED_Pin GPIO_PIN_14
#define STATUS_SOURIS_LED_GPIO_Port GPIOC
#define STATUS_CHAT_LED_Pin GPIO_PIN_15
#define STATUS_CHAT_LED_GPIO_Port GPIOC
#define BOUTON_RESET_Pin GPIO_PIN_10
#define BOUTON_RESET_GPIO_Port GPIOG
#define ENC1_PH1_Pin GPIO_PIN_0
#define ENC1_PH1_GPIO_Port GPIOA
#define ENC1_PH2_Pin GPIO_PIN_1
#define ENC1_PH2_GPIO_Port GPIOA
#define LIDAR_RX_Pin GPIO_PIN_2
#define LIDAR_RX_GPIO_Port GPIOA
#define PWM_Mot1_CH1_Pin GPIO_PIN_6
#define PWM_Mot1_CH1_GPIO_Port GPIOA
#define PWM_Mot1_CH2_Pin GPIO_PIN_7
#define PWM_Mot1_CH2_GPIO_Port GPIOA
#define PWM_Mot2_CH1_Pin GPIO_PIN_0
#define PWM_Mot2_CH1_GPIO_Port GPIOB
#define PWM_Mot2_CH2_Pin GPIO_PIN_1
#define PWM_Mot2_CH2_GPIO_Port GPIOB
#define Bluetooth_TX_Pin GPIO_PIN_10
#define Bluetooth_TX_GPIO_Port GPIOB
#define Bluetooth_RX_Pin GPIO_PIN_11
#define Bluetooth_RX_GPIO_Port GPIOB
#define ACC_INT2_Pin GPIO_PIN_12
#define ACC_INT2_GPIO_Port GPIOB
#define ACC_INT1_Pin GPIO_PIN_13
#define ACC_INT1_GPIO_Port GPIOB
#define LIDAR_M_CTR_Pin GPIO_PIN_8
#define LIDAR_M_CTR_GPIO_Port GPIOA
#define VCP_TX_Pin GPIO_PIN_9
#define VCP_TX_GPIO_Port GPIOA
#define VCP_RX_Pin GPIO_PIN_10
#define VCP_RX_GPIO_Port GPIOA
#define ENC2_PH1_Pin GPIO_PIN_11
#define ENC2_PH1_GPIO_Port GPIOA
#define ENC2_PH2_Pin GPIO_PIN_12
#define ENC2_PH2_GPIO_Port GPIOA
#define TOF1_XSHUT_Pin GPIO_PIN_15
#define TOF1_XSHUT_GPIO_Port GPIOA
#define TOF2_XSHUT_Pin GPIO_PIN_10
#define TOF2_XSHUT_GPIO_Port GPIOC
#define TOF3_XSHUT_Pin GPIO_PIN_11
#define TOF3_XSHUT_GPIO_Port GPIOC
#define TOF4_XSHUT_Pin GPIO_PIN_3
#define TOF4_XSHUT_GPIO_Port GPIOB
#define TOF1_GPIO_Pin GPIO_PIN_4
#define TOF1_GPIO_GPIO_Port GPIOB
#define TOF1_GPIO_EXTI_IRQn EXTI4_IRQn
#define TOF2_GPIO_Pin GPIO_PIN_5
#define TOF2_GPIO_GPIO_Port GPIOB
#define TOF2_GPIO_EXTI_IRQn EXTI9_5_IRQn
#define TOF3_GPIO_Pin GPIO_PIN_6
#define TOF3_GPIO_GPIO_Port GPIOB
#define TOF3_GPIO_EXTI_IRQn EXTI9_5_IRQn
#define TOF4_GPIO_Pin GPIO_PIN_7
#define TOF4_GPIO_GPIO_Port GPIOB
#define TOF4_GPIO_EXTI_IRQn EXTI9_5_IRQn

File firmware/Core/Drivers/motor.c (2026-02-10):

#include "motor.h"
#include <stdlib.h>
#include <math.h>

void Motor_Init(Motor_Handle_t* hmotor) {
    if (hmotor == NULL) return;

    // Start PWM channels
    HAL_TIM_PWM_Start(hmotor->pwm_timer, hmotor->channel_fwd);
    HAL_TIM_PWM_Start(hmotor->pwm_timer, hmotor->channel_rev);

    // Start encoder timer
    HAL_TIM_Encoder_Start(hmotor->enc_timer, TIM_CHANNEL_ALL);

    hmotor->enc_prev_counter = __HAL_TIM_GET_COUNTER(hmotor->enc_timer);
    hmotor->total_ticks = 0;
    hmotor->speed_rpm = 0.0f;
    hmotor->speed_rad_s = 0.0f;

    // Ramp Init
    hmotor->current_pwm = 0.0f;
    hmotor->target_pwm = 0.0f;
    hmotor->pwm_ramp_step = 5.0f;
}

void Motor_SetSpeed(Motor_Handle_t* hmotor, float pwm_percent) {
    if (hmotor == NULL) return;

    // Clamp target
    if (pwm_percent > 100.0f) pwm_percent = 100.0f;
    else if (pwm_percent < -100.0f) pwm_percent = -100.0f;

    hmotor->target_pwm = pwm_percent;
}

void Motor_UpdatePWM(Motor_Handle_t* hmotor) {
    if (hmotor == NULL) return;

    // Ramping Logic
    float diff = hmotor->target_pwm - hmotor->current_pwm;
    
    if (diff > hmotor->pwm_ramp_step) {
        hmotor->current_pwm += hmotor->pwm_ramp_step;
    } else if (diff < -hmotor->pwm_ramp_step) {
        hmotor->current_pwm -= hmotor->pwm_ramp_step;
    } else {
        hmotor->current_pwm = hmotor->target_pwm;
    }

    // Apply to Hardware
    float applied_pwm = hmotor->current_pwm;
    uint32_t duty_cycle = (uint32_t)(fabs(applied_pwm) * hmotor->pwm_timer->Init.Period / 100.0f);

    if (applied_pwm > 0) { // Forward
        __HAL_TIM_SET_COMPARE(hmotor->pwm_timer, hmotor->channel_fwd, duty_cycle);
        __HAL_TIM_SET_COMPARE(hmotor->pwm_timer, hmotor->channel_rev, 0);
    } else if (applied_pwm < 0) { // Reverse
        __HAL_TIM_SET_COMPARE(hmotor->pwm_timer, hmotor->channel_fwd, 0);
        __HAL_TIM_SET_COMPARE(hmotor->pwm_timer, hmotor->channel_rev, duty_cycle);
    } else { // Stop
        __HAL_TIM_SET_COMPARE(hmotor->pwm_timer, hmotor->channel_fwd, 0);
        __HAL_TIM_SET_COMPARE(hmotor->pwm_timer, hmotor->channel_rev, 0);
    }
}

void Motor_UpdateSpeed(Motor_Handle_t* hmotor, float delta_time_s) {
    if (hmotor == NULL || delta_time_s == 0.0f) return;

    int32_t current_counter = __HAL_TIM_GET_COUNTER(hmotor->enc_timer);
    int32_t delta_ticks;

    if (hmotor->enc_timer->Init.Period <= 65535) { // 16-bit timer
        delta_ticks = (int16_t)(current_counter - hmotor->enc_prev_counter);
    } else { // 32-bit timer
        delta_ticks = current_counter - hmotor->enc_prev_counter;
    }

    hmotor->enc_prev_counter = current_counter;
    hmotor->total_ticks += delta_ticks;

    float revolutions_per_second = (float)delta_ticks / (float)hmotor->enc_resolution / delta_time_s;
    hmotor->speed_rpm = revolutions_per_second * 60.0f;
    hmotor->speed_rad_s = revolutions_per_second * 2.0f * M_PI;
}

void Motor_ResetEncoder(Motor_Handle_t* hmotor) {
    if (hmotor == NULL) return;

    // Reset Hardware Counter
    __HAL_TIM_SET_COUNTER(hmotor->enc_timer, 0);

    // Reset Internal Variables
    hmotor->enc_prev_counter = 0;
    hmotor->total_ticks = 0;
    hmotor->speed_rpm = 0.0f;
    hmotor->speed_rad_s = 0.0f;
}

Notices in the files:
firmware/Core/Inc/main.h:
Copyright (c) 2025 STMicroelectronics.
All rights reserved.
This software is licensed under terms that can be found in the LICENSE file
